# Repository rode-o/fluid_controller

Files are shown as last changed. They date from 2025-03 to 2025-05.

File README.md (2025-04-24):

# Fluid Controller
# WIP

This repository contains software and firmware for a custom fluid control system, featuring PID-based flow rate control, intuitive graphical interfaces, real-time plotting, and reliable hardware communication.

---

## Overview

The project includes two primary components:

- **Controller Interface (GUI)**: A Python-based graphical user interface for real-time monitoring, PID tuning, and easy control of the fluid system.
- **PID Controller (Firmware)**: Arduino-compatible firmware implementing precise PID flow control, valve actuation, sensor reading, and communication logic.

---

## Repository Structure

```
fluid_controller/
│  README.md
│  pid_controller.zip
│
├─ controller_interface/           # PyQt GUI application
│  │  build.bat
│  │  Controller_Interface.spec
│  │  LICENSE
│  │  pyproject.toml
│  │  requirements.txt
│  ├─ build/ …                     # (auto-generated by PyInstaller)
│  ├─ dist/  …                     # frozen executables
│  ├─ src/
│  │  ├─ controller_interface/
│  │  │  ├─ controller/            # high-level UI controller classes
│  │  │  ├─ model/                 # data & serial back-end
│  │  │  ├─ view/                  # views, panels, widgets, themes, plots
│  │  │  ├─ resources/             # .qrc + compiled resources_rc.py
│  │  │  └─ utils/                 # logging & path helpers
│  │  └─ test/                     # GUI unit/integration tests
│  └─ README.md                    # GUI-specific notes
│
├─ curve_tools/                    # ad-hoc analysis / plotting scripts
│  ├─ exp_curve_validation.py
│  └─ plotter.py
│
├─ misc_utils/                     # one-off utilities / images
│  ├─ DOT.py
│  └─ run_tree.png
│
├─ pid_controller/                 # Embedded firmware (Arduino / C++)
│  └─ _controller/
│     ├─ _controller.ino           # entry-point sketch
│     ├─ config.*                  # system-wide constants
│     ├─ pid.*                     # core PID engine
│     ├─ exp_control.*             # exponential gain scheduling
│     ├─ sigmoidal_control.*       # (optional) sigmoidal gain scheduling
│     ├─ constant_voltage_control.*# open-loop calibration mode
│     ├─ filter.*                  # adaptive + EMA filters
│     ├─ flow.*                    # I²C flow-sensor driver
│     ├─ bartels.*                 # pump DAC driver
│     ├─ display.*, buttons.*      # OLED + input HW
│     ├─ report.*                  # CSV / JSON telemetry
│     └─ system_state.h            # shared data struct
│
├─ test_hardware/                  # standalone sketches for bench tests
│  ├─ i2c_check/…
│  ├─ test_buttons/…
│  ├─ test_i2c/…
│  └─ test_sensor/…                # sensor sanity checks
└─ flow_volume.json                # per-concentration flow-volume map

```

---

## Features

### Controller Interface (GUI)

- Real-time data visualization and PID tuning
- User-friendly layout with customizable themes
- Direct serial communication to embedded hardware
- Easy-to-use GUI controls for hardware interaction

### PID Controller Firmware

- Accurate PID control algorithm with dynamic tuning
- Flow rate measurement and regulation
- Adaptive gain control via sigmoidal functions
- Reliable serial communication for GUI integration

---

## Getting Started

### GUI Installation & Usage

**Prerequisites**:

- Python (≥ 3.8)
- Required Python packages (PyQt6/PySide6, numpy, matplotlib)

**Installation**:

```bash
cd controller_interface
pip install -r requirements.txt
```

**Running the GUI**:

```bash
python src/controller_interface/main.py
```

**Building Standalone Executable (Windows)**:

```bash
./build.bat
```

### Firmware Installation & Upload (Arduino)

1. Open the Arduino IDE.
2. Load the sketch `_controller/_controller.ino`.
3. Connect the Arduino board to your computer via USB.
4. Select your Arduino model and COM port.
5. Compile and upload the sketch to the board.

---

## Hardware Testing

Inside the `test_hardware/` folder, you'll find Arduino sketches designed to test:

- I²C communication (`i2c_check`, `test_i2c`)
- Flow sensors (`test_sensor`, `test_sensor_2`)
- Buttons and other inputs (`test_buttons`)

Load these sketches onto your Arduino hardware for troubleshooting and verification purposes.

---

## Dependencies

- Python ≥ 3.8
- PyQt6 / PySide6 (listed in `requirements.txt`)
- numpy, matplotlib (listed in `requirements.txt`)
- Arduino IDE (for firmware)

- Email: [ropeters@valdosta.edu]

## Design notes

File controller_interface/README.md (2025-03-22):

# Fluid Controller
# WIP

This repository contains software and firmware for a custom fluid control system, featuring PID-based flow rate control, intuitive graphical interfaces, real-time plotting, and reliable hardware communication.

---

## Overview

The project includes two primary components:

- **Controller Interface (GUI)**: A Python-based graphical user interface for real-time monitoring, PID tuning, and easy control of the fluid system.
- **PID Controller (Firmware)**: Arduino-compatible firmware implementing precise PID flow control, valve actuation, sensor reading, and communication logic.

---

## Repository Structure

```
fluid_controller/
├── controller_interface/     # GUI software (Python)
│   ├── build/                # Build files
│   ├── dist/                 # Distributable executables
│   └── src/                  # Source code for GUI
│       ├── controller_interface/
│       │   ├── core/         # Backend logic and communication
│       │   ├── gui/          # Graphical interface elements
│       │   └── resources/    # Icons and images
│       └── test/             # Testing scripts
│
├── pid_controller/           # Arduino firmware (C++)
│   └── _controller/
│       ├── config.h/cpp      # System configurations
│       ├── pid.h/cpp         # PID controller logic
│       ├── flow.h/cpp        # Flow sensor logic
│       ├── sigmoidal_control.h/cpp # Advanced gain scheduling
│       └── _controller.ino   # Main Arduino sketch
│
├── test_hardware/            # Arduino sketches for hardware testing
│
├── flow_volume.json          # Flow volume configuration data
├── pid_controller.zip        # Archive of PID controller code
└── README.md                 # Project documentation
```

---

## Features

### Controller Interface (GUI)

- Real-time data visualization and PID tuning
- User-friendly layout with customizable themes
- Direct serial communication to embedded hardware
- Easy-to-use GUI controls for hardware interaction

### PID Controller Firmware

- Accurate PID control algorithm with dynamic tuning
- Flow rate measurement and regulation
- Adaptive gain control via sigmoidal functions
- Reliable serial communication for GUI integration

---

## Getting Started

### GUI Installation & Usage

**Prerequisites**:

- Python (≥ 3.8)
- Required Python packages (PyQt6/PySide6, numpy, matplotlib)

**Installation**:

```bash
cd controller_interface
pip install -r requirements.txt
```

**Running the GUI**:

```bash
python src/controller_interface/main.py
```

**Building Standalone Executable (Windows)**:

```bash
./build.bat
```

### Firmware Installation & Upload (Arduino)

1. Open the Arduino IDE.
2. Load the sketch `_controller/_controller.ino`.
3. Connect the Arduino board to your computer via USB.
4. Select your Arduino model and COM port.
5. Compile and upload the sketch to the board.

---

## Hardware Testing

Inside the `test_hardware/` folder, you'll find Arduino sketches designed to test:

- I²C communication (`i2c_check`, `test_i2c`)
- Flow sensors (`test_sensor`, `test_sensor_2`)
- Buttons and other inputs (`test_buttons`)

Load these sketches onto your Arduino hardware for troubleshooting and verification purposes.

---

## Dependencies

- Python ≥ 3.8
- PyQt6 / PySide6 (listed in `requirements.txt`)
- numpy, matplotlib (listed in `requirements.txt`)
- Arduino IDE (for firmware)

- Email: [ropeters@valdosta.edu]

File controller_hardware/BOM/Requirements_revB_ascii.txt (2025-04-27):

# Solenoid Controller — Manufacturing Package (rev‑B)

* USB‑C PD sink requests 20 V @ 3 A (fallback 15/9/5 V).
* Rails: 24 V (≤2 A) via boost; 3.3 V logic; low‑noise LDO for RF & sensors.
* Actuation: DRV8912‑Q1 drives three Bürkert 6724 valves (100 mA hit, 25 mA hold).
* Pump: mp‑Lowdriver module powers Bartels BP7.
* Flow feedback: Sensirion SLF3S‑0600F via I²C.
* Status RGB LED indicates PD state & faults.
* ESP32‑S3 handles PWM, closed‑loop control, Wi‑Fi comms.

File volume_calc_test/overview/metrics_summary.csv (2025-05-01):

test_name | final_flow_ml | total_time_raw_s | total_time_raw_min | total_volume_raw_ml | total_mass_raw_g | avg_flow_raw | max_flow_raw | avg_temp_raw | total_time_stable_s | total_time_stable_min | total_volume_stable_ml | total_mass_stable_g | avg_flow_stable | max_flow_stable | min_flow_stable | std_flow_stable | rstd_flow_stable | cov_flow_stable | avg_temp_stable | min_temp_stable | max_temp_stable | measured_mass_g | mass_error_pct
cartridge_flow_test_cal_RodePeters_20250429_112158 | 19.3018 | 2335.837 | 38.9306 | 19.3027 | 18.8588 | 0.4962 | 0.551 | 22.2603 | 2255.413 | 37.5902 | 18.7122 | 18.2818 | 0.4978 | 0.54 | 0.47 | 0.005 | 1.0134 | 0.0101 | 22.2525 | 21.78 | 22.67 | 20.36 | 7.960209557341935
cartridge_flow_test_5_RodePeters_20250429_152344 | 15.2667 | 1841.395 | 30.6899 | 15.2667 | 14.9156 | 0.4978 | 0.603 | 23.9297 |  |  |  |  |  |  |  |  |  |  |  |  |  | 15.1 | 1.2362895223792547
cartridge_flow_test_4_RodePeters_20250429_144302 | 18.339 | 2220.019 | 37.0003 | 18.3394 | 17.9176 | 0.4961 | 1.185 | 23.704 | 2137.613 | 35.6269 | 17.744 | 17.3359 | 0.498 | 1.185 | 0.351 | 0.0097 | 1.9479 | 0.0195 | 23.7003 | 23.28 | 24.0 | 17.87 | -0.2656605795418984
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

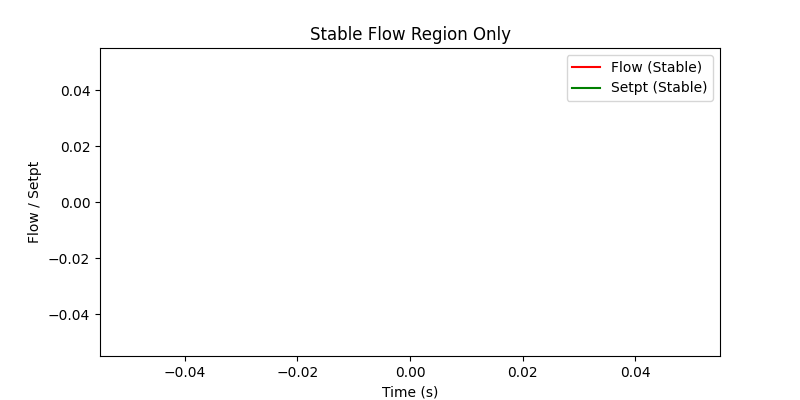
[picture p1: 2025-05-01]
data_demo_1/demo_1_RodePeters_20250508_111236/processed/stable_data/plots/stable_data_plot.png

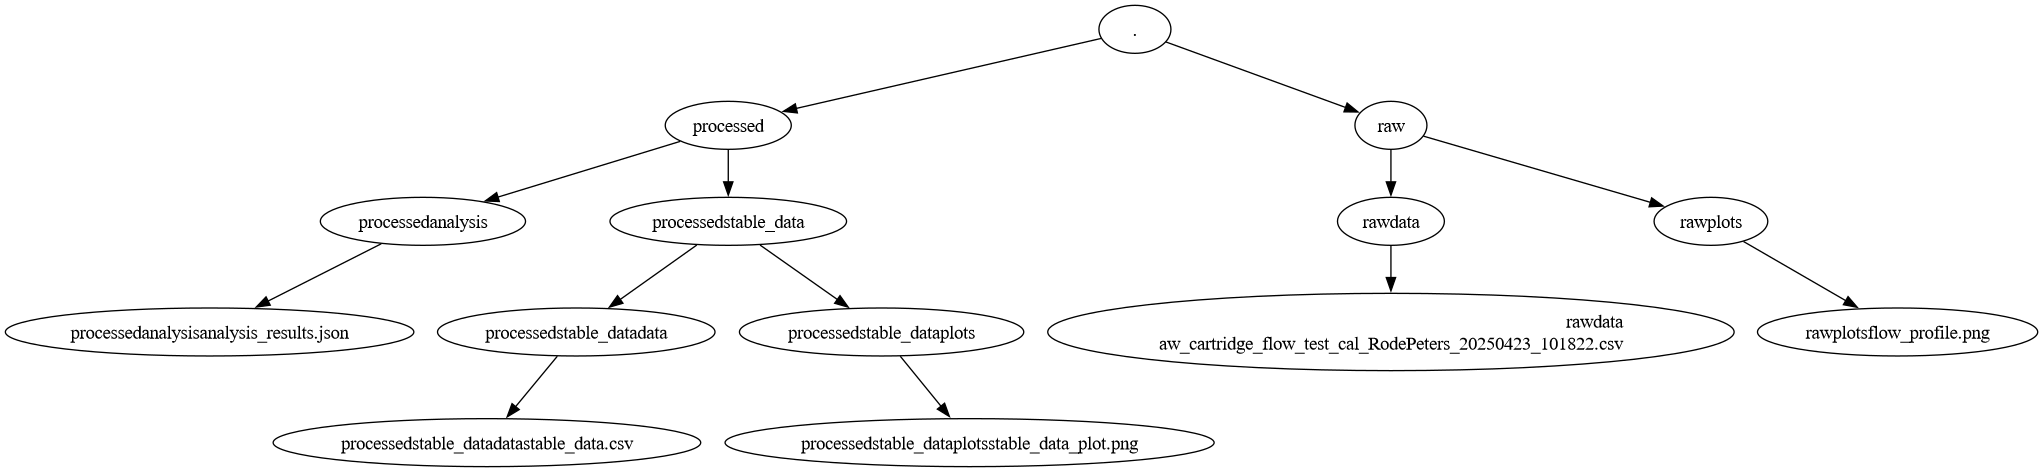
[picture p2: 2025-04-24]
misc_utils/run_tree.png

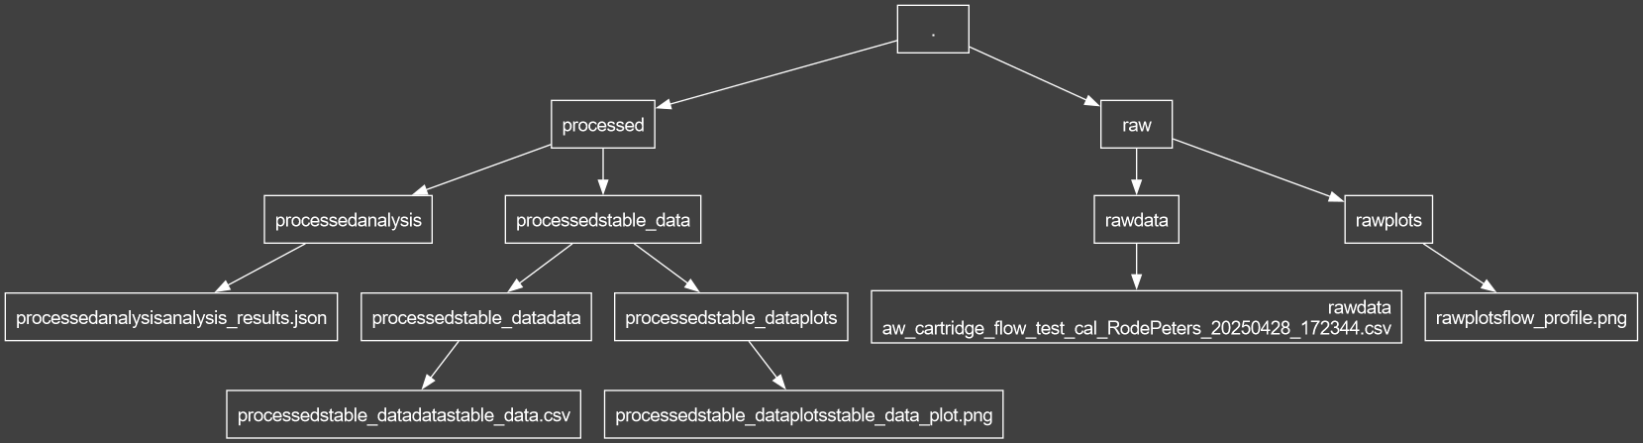
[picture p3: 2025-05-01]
misc_utils/run_tree_white.png

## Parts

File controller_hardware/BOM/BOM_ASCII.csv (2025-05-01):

Part | Ref | Qty | Description | Mfr PN | Digi-Key PN | Unit $ | Ext $
USB4085-GF-A | J1 | 1 | USB-C receptacle, USB2 | GCT USB4085-GF-A | 2073-USB4085-GF-A-ND | 0.65 | 0.65
STUSB4500QTR | U1 | 1 | USB-PD sink controller | ST STUSB4500QTR | 497-18666-1-ND | 2.95 | 2.95
CSD17573Q5B | Q1 | 1 | N‑FET 40V 4.5mOhm | TI CSD17573Q5B | 296-40204-1-ND | 0.45 | 0.45
WE-CAP 220uF 35V | C1 | 1 | Hybrid polymer capacitor | Wurth 860020673012 | 732-860020673012-ND | 0.6 | 0.6
TPS62177DQC | U2 | 1 | Buck 3.3V 0.5A | TI TPS62177DQC | 296-42071-1-ND | 1.19 | 1.19
WE-MPSB 10uH | L1 | 1 | Inductor shielded 10uH 1.6A | Wurth 7447749100 | 732-7447749100-ND | 0.42 | 0.42
TPS73633DBVT | U10 | 1 | LDO 3.3V 400mA | TI TPS73633DBVT | 296-15952-1-ND | 1.22 | 1.22
TPS55340PWP | U3 | 1 | Boost controller 20V to 24V | TI TPS55340PWP | 296-20726-1-ND | 1.74 | 1.74
WE-MAPI 4.7uH | L2 | 1 | Inductor shielded 4.7uH 9A | Wurth 74438357047 | 732-74438357047-ND | 1.08 | 1.08
DRV8908BQPW | U4 | 1 | 4 full-bridge driver | TI DRV8908BQPW | 296-50867-1-ND | 3.95 | 3.95
WE-CAP 47uF 35V | C2 | 1 | Hybrid polymer capacitor | Wurth 860020673006 | 732-860020673006-ND | 0.48 | 0.48
053261-0471 | J2 | 1 | PicoBlade header 4pos | Molex 053261-0471 | WM1734-ND | 0.45 | 0.45
053261-0671 | J3 | 1 | PicoBlade header 6pos | Molex 053261-0671 | WM1736-ND | 0.55 | 0.55
S2B-PH-K-S | J5-J7 | 3 | JST PH header 2pos vert | JST S2B-PH-K-S | 455-1703-ND | 0.1 | 0.30000000000000004
WL-SMCW 150060RS75000 | LED1 | 1 | RGB LED 0603 common anode | Wurth 150060RS75000 | 732-11825-1-ND | 0.19 | 0.19
ESP32-S3-WROOM-1-N8 | U7 | 1 | ESP32-S3 module 8MB | Espressif | 1965-ESP32-S3-WROOM-1-N8-ND | 3.4 | 3.4
110-44-318-41-001000 | J4 | 1 | 18pin socket | Mill‑Max 110-44-318-41-001000 | 110-44-318-41-001000-ND | 2.44 | 2.44
mp-Lowdriver | U8 | 1 | Piezo driver module | Bartels | NA | 42.0 | 42.0
BP7 micropump | PUMP1 | 1 | Piezo micropump | Bartels BP7 | NA | 69.0 | 69.0
SLF3S-0600F | FL1 | 1 | Flow sensor 0‑600uL/min | Sensirion SLF3S‑0600F | 1649-SLF3S-0600F-ND | 29.5 | 29.5
Burkert 6724 valve | V1‑V3 | 3 | 24V micro valve | Burkert 6724 | NA | 58.0 | 174.0
TPD2E2U06DRLR | TVS1 | 1 | USB ESD diode 2‑line | TI TPD2E2U06DRLR | 296‑39231‑1‑ND | 0.25 | 0.25
SBR5U60P5 | D1 | 1 | Schottky 40V 5A | TI SBR5U60P5 | 296‑50472‑1‑ND | 0.3 | 0.3
Misc passives | - | 1 | 0603 resistors capacitors | Various | - | 3.0 | 3.0

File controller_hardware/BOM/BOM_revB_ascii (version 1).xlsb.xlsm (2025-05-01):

Part | Refs | Qty | Description | Manufacturer PN | Digi-Key PN | Ratings | Unit $ | Ext $
USB4085-GF-A | J1 | 1 | USB-C receptacle, USB2 only | GCT USB4085-GF-A | 2073-USB4085-GF-A-ND | 5 A, 25 V, 20k cycles | 0.63 | 0.63
STUSB4500QTR | U1 | 1 | USB-PD sink / power path | ST STUSB4500QTR | 497-18666-1-ND | 5-20 V, 5 A | 3.04 | 3.04
CSD17573Q5B | Q1 | 1 | Power-path N-FET 40 V 4.5 mOhm | TI CSD17573Q5B | 296-40204-1-ND | Id 120 A | 0.45 | 0.45
EEE-FK1V221P | C1 | 1 | Cap 220 uF 35 V | Panasonic EEU-FR1V221L | 667-EEU-FR1V221LCT-ND | ESR 70 mOhm | 0.32 | 0.32
TPS62177DQC | U2 | 1 | Buck 3.3 V 0.5 A | TI TPS62177DQC | 296-42071-1-ND | Vin 4.5-28 V | 1.19 | 1.19
LQH44PN100MPRL | L1 | 1 | Inductor 10 uH 1.2 A | Murata LQH44PN100MPRL | 490-2523-1-ND | DCR 120 mOhm | 0.38 | 0.38
TPS73633DBVT | U10 | 1 | LDO 3.3 V 400 mA | TI TPS73633DBVT | 296-15952-1-ND | Dropout 340 mV | 1.22 | 1.22
TPS55340PWP | U3 | 1 | Boost 20 V to 24 V | TI LM5157DGKR | 296-LM5157DGKR-ND | Switch 42 V 4 A | 2.7 | 2.7
74438357047 | L2 | 1 | Inductor 4.7 uH 8 A | Coilcraft XAL5050-472MEB | 1783-1616-1-ND | DCR 14 mOhm | 1.34 | 1.34
DRV8908BQPW | U4 | 1 | 12-ch half-bridge driver | TI DRV8912-Q1 | 296-54932-1-ND | 40 V, 2 A pk/channel | 4.95 | 4.95
EEE-FK1V470P | C2 | 1 | Cap 47 uF 35 V | Panasonic EEU-FR1V470 | 667-EEU-FR1V470CT-ND | ESR 80 mOhm | 0.28 | 0.28
053261-0471 | J2 | 1 | PicoBlade header 4 pos | Molex 053261-0471 | WM1734-ND | 1 A pin | 0.45 | 0.45
053261-0671 | J3 | 1 | PicoBlade header 6 pos | Molex 053261-0671 | WM1736-ND | 1 A pin | 0.55 | 0.55
S2B-PH-K-S | J5-J7 | 3 | JST PH header 2 pos | JST B2B-PH-KL | 455-1666-1-ND | 3 A pin | 0.12 | 0.36
WL-SMCW 150060RS75000 | LED1 | 1 | RGB LED 0603 | SunLED XZCMECBDDGK53W | 1497-1610-1-ND | 20 mA per color | 0.28 | 0.28
ESP32-S3-WROOM-1-N8 | U7 | 1 | ESP32-S3 module 8 MB | Espressif ESP32-S3-WROOM-1-N8 | 1965-ESP32-S3-WROOM-1-N8-ND | 3.3 V, 500 mA peak | 3.4 | 3.4
110-44-318-41-001000 | J4 | 1 | 18-pin DIP socket | Mill-Max 110-44-318-41-001000 | 110-44-318-41-001000-ND | 1 A pin | 2.44 | 2.44
mp-Lowdriver | U8 | 1 | Piezo driver module | Bartels mp-Lowdriver | NA | +-75 Vpp | 42 | 42
BP7 micropump | PUMP1 | 1 | Piezo micropump | Bartels BP7 | NA | 24 V act, 800 mW | 69 | 69
SLF3S-0600F | FL1 | 1 | Flow sensor 0-600 uL/min | Sensirion SLF3S-0600F | 1649-SLF3S-0600F-ND | 3.3 V, 5 mA | 29.5 | 29.5
Burkert 6724 valve | VALVE1-3 | 3 | Micro solenoid valve 24 V | Burkert 6724 | NA | 24 V 100 mA hit | 58 | 174
TPD2E2U06DRLR | TVS1 | 1 | USB ESD protector | Nexperia PESD5VDUO | 1727-1251-1-ND | +-15 kV | 0.16 | 0.16
Misc passives | - | 1 | Assorted resistors capacitors | Yageo / TDK | NA | Various | 3 | 3

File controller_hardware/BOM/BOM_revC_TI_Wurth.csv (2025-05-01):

Part | Refs | Qty | Description | Manufacturer PN | Digi-Key PN | Unit $ | Ext $
USB4085-GF-A | J1 | 1 | USB‑C receptacle, USB2 | GCT USB4085-GF-A | 2073-USB4085-GF-A-ND | 0.65 | 0.65
STUSB4500QTR | U1 | 1 | USB‑PD sink / power path | ST STUSB4500QTR | 497-18666-1-ND | 2.95 | 2.95
CSD17573Q5B | Q1 | 1 | N‑FET 40 V 4.5 mΩ | TI CSD17573Q5B | 296-40204-1-ND | 0.45 | 0.45
WE‑CAP 220 µF 35 V | C1 | 1 | Hybrid‑polymer bulk cap | Würth 860020673012 | 732-860020673012-ND | 0.6 | 0.6
TPS62177DQC | U2 | 1 | Buck 3.3 V 0.5 A | TI TPS62177DQC | 296-42071-1-ND | 1.19 | 1.19
WE‑MPSB 10 µH | L1 | 1 | Inductor 10 µH 1.6 A | Würth 7447749100 | 732-7447749100-ND | 0.42 | 0.42
TPS73633DBVT | U10 | 1 | LDO 3.3 V 400 mA | TI TPS73633DBVT | 296-15952-1-ND | 1.22 | 1.22
TPS55340PWP | U3 | 1 | Boost ctrl 20→24 V | TI TPS55340PWP | 296-20726-1-ND | 1.74 | 1.74
WE‑MAPI 4.7 µH | L2 | 1 | Inductor 4.7 µH 9 A | Würth 74438357047 | 732-74438357047-ND | 1.08 | 1.08
DRV8908BQPW | U4 | 1 | 8‑half‑bridge driver | TI DRV8908BQPW | 296-50867-1-ND | 3.95 | 3.95
WE‑CAP 47 µF 35 V | C2 | 1 | Hybrid‑polymer cap | Würth 860020673006 | 732-860020673006-ND | 0.48 | 0.48
053261-0471 | J2 | 1 | PicoBlade 4‑pos HDR | Molex 053261‑0471 | WM1734-ND | 0.45 | 0.45
053261-0671 | J3 | 1 | PicoBlade 6‑pos HDR | Molex 053261‑0671 | WM1736-ND | 0.55 | 0.55
S2B-PH-K-S | J5‑J7 | 3 | JST‑PH 2‑pos HDR vert | JST S2B-PH-K-S | 455-1703-ND | 0.1 | 0.30000000000000004
WL‑SMCW 150060RS75000 | LED1 | 1 | RGB LED 0603 CA | Würth 150060RS75000 | 732-11825-1-ND | 0.19 | 0.19
ESP32-S3-WROOM-1-N8 | U7 | 1 | ESP32‑S3 module 8 MB | Espressif | 1965-ESP32-S3-WROOM-1-N8-ND | 3.4 | 3.4
110-44-318-41-001000 | J4 | 1 | 18‑pin socket | Mill‑Max 110‑44‑318‑41‑001000 | 110-44-318-41-001000-ND | 2.44 | 2.44
mp‑Lowdriver | U8 | 1 | Piezo driver module | Bartels | — | 42.0 | 42.0
BP7 micropump | PUMP1 | 1 | Piezo micropump | Bartels BP7 | — | 69.0 | 69.0
SLF3S-0600F | FL1 | 1 | Flow sensor 0‑600 µL/min | Sensirion SLF3S‑0600F | 1649-SLF3S-0600F-ND | 29.5 | 29.5
Burkert 6724 valve | V1‑V3 | 3 | 24 V micro valve | Burkert 6724 | — | 58.0 | 174.0
TPD2E2U06DRLR | TVS1 | 1 | USB ESD diode 2‑line | TI TPD2E2U06DRLR | 296-39231-1-ND | 0.25 | 0.25
SBR5U60P5 | D1 | 1 | Schottky 40 V 5 A | TI SBR5U60P5 | 296-50472-1-ND | 0.3 | 0.3
Misc passives | - | 1 | Rs/Cs, RT, COMP, pull‑ups | — | — | 3.0 | 3.0

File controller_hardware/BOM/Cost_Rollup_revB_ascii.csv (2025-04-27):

Part | Qty | Unit $ | Ext $
USB4085-GF-A | 1 | 0.63 | 0.63
STUSB4500QTR | 1 | 3.04 | 3.04
CSD17573Q5B | 1 | 0.45 | 0.45
EEU-FR1V221L | 1 | 0.32 | 0.32
TPS62177DQC | 1 | 1.19 | 1.19
LQH44PN100MPRL | 1 | 0.38 | 0.38
TPS73633DBVT | 1 | 1.22 | 1.22
LM5157DGKR | 1 | 2.7 | 2.7
XAL5050-472MEB | 1 | 1.34 | 1.34
DRV8912-Q1 | 1 | 4.95 | 4.95
EEU-FR1V470 | 1 | 0.28 | 0.28
053261-0471 | 1 | 0.45 | 0.45
053261-0671 | 1 | 0.55 | 0.55
B2B-PH-KL | 3 | 0.12 | 0.36
XZCMECBDDGK53W | 1 | 0.28 | 0.28
ESP32-S3-WROOM-1-N8 | 1 | 3.4 | 3.4
110-44-318-41-001000 | 1 | 2.44 | 2.44
mp-Lowdriver | 1 | 42.0 | 42.0
BP7 micropump | 1 | 69.0 | 69.0
SLF3S-0600F | 1 | 29.5 | 29.5
Burkert 6724 valve | 3 | 58.0 | 174.0
PESD5VDUO | 1 | 0.16 | 0.16
Misc passives | 1 | 3.0 | 3.0

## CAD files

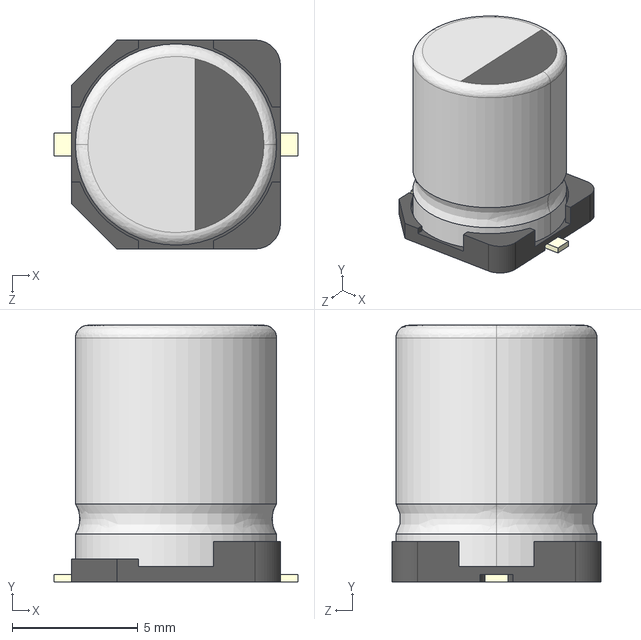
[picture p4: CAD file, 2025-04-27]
controller_hardware/eda/EEE-FK1V221P/EEEFK1V221P.step
9.70 x 10.2 x 8.30 mm

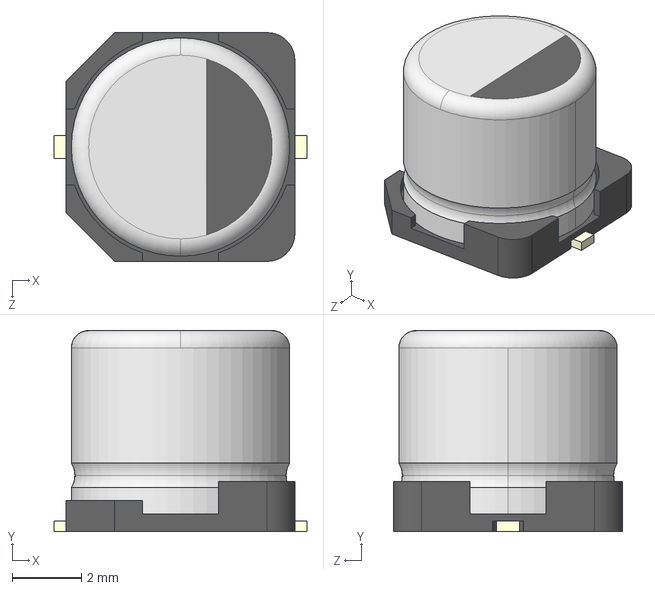
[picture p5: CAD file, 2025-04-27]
controller_hardware/eda/EEE-FK1V470P/EEEFK1V470P.step
7.30 x 5.80 x 6.60 mm

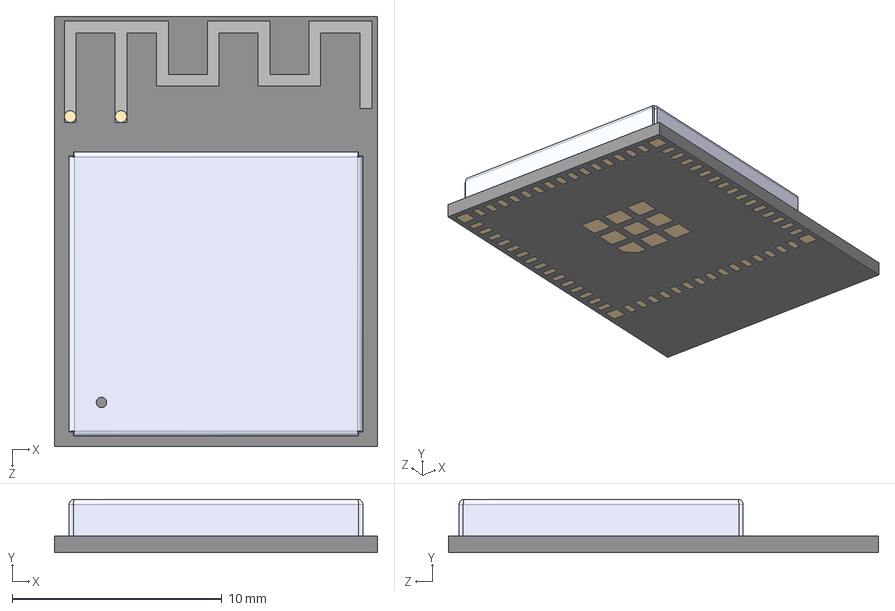
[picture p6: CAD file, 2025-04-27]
controller_hardware/eda/ESP32-S3-MINI-1-N8/ESP32-S3-MINI-1-N8.step
15.4 x 2.55 x 20.5 mm

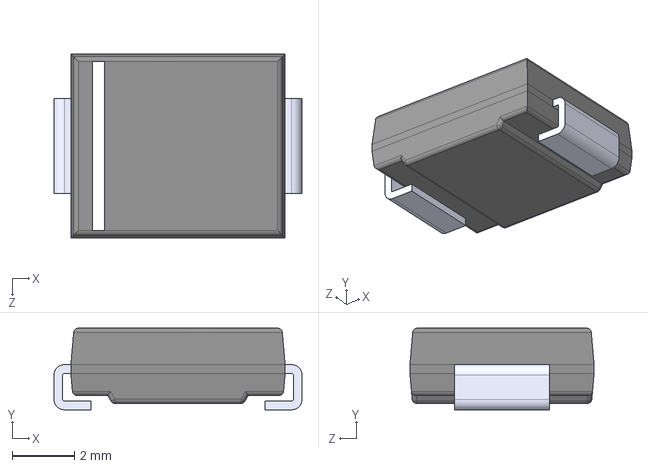
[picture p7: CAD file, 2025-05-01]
controller_hardware/eda/MBRS540T3G/MBRS540T3G.step
7.95 x 2.62 x 5.91 mm

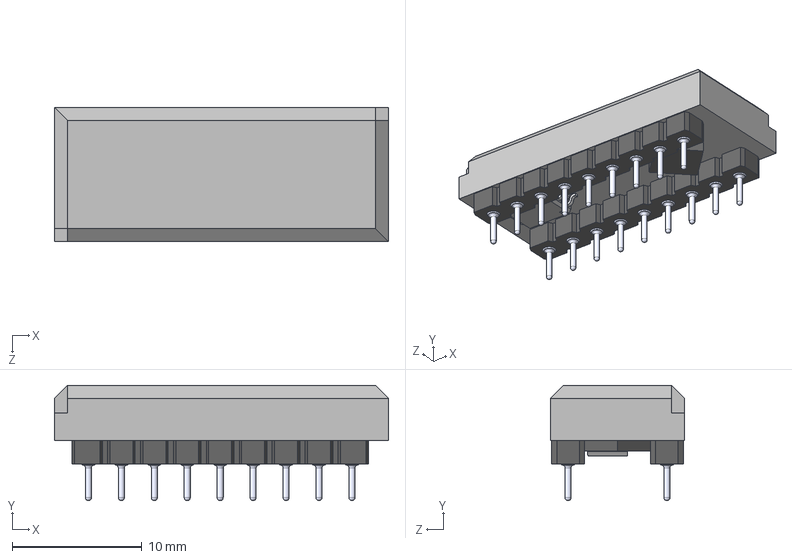
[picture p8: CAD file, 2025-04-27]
controller_hardware/eda/mp_lowdriver---110-87-318-41-001101/mp-Lowdriver 3D model.STEP
25.8 x 8.89 x 10.3 mm
Platine
0603_AVX
D1
pcb_connector_350-80-109-00-019101 x 2
C3
C2
DE41, DE42 x 2
CE41, CE42 x 2
U2
C2 Mitte
C1 Seiten x 2
DE43, DE44 Mitte x 2
D1-SOD323_DIO.step x 4
R11 x 2
U1
L1
Coating_Highdriver

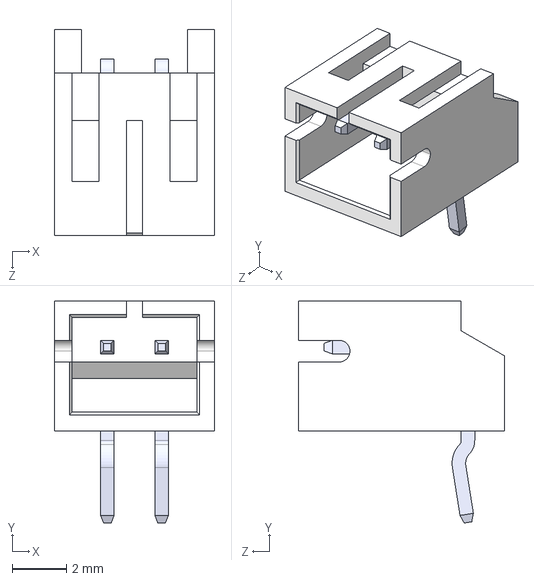
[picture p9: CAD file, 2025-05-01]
controller_hardware/eda/S2B-PH-K-S/S2B-PH-K-S.STEP
5.90 x 8.18 x 7.60 mm

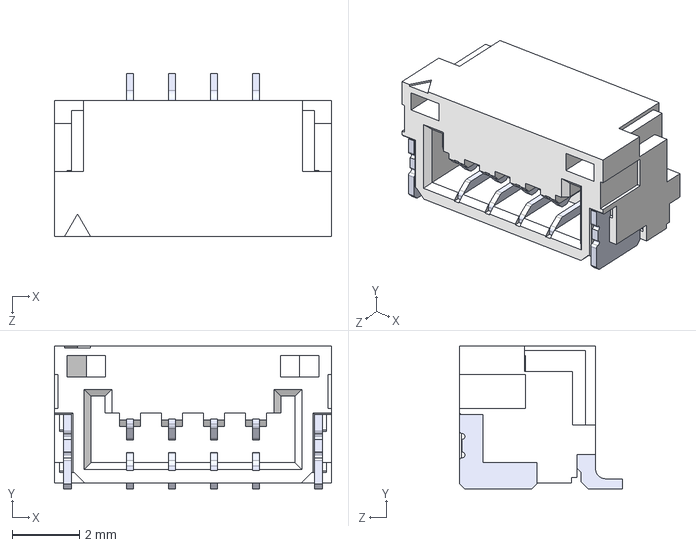
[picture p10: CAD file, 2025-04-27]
controller_hardware/eda/SM04B-GHS-TB_LF__SN_-/SM04B-GHS-TB_LF__SN_-.step
8.25 x 4.25 x 4.85 mm
SMxB-GHS-TB_04
pin x 4

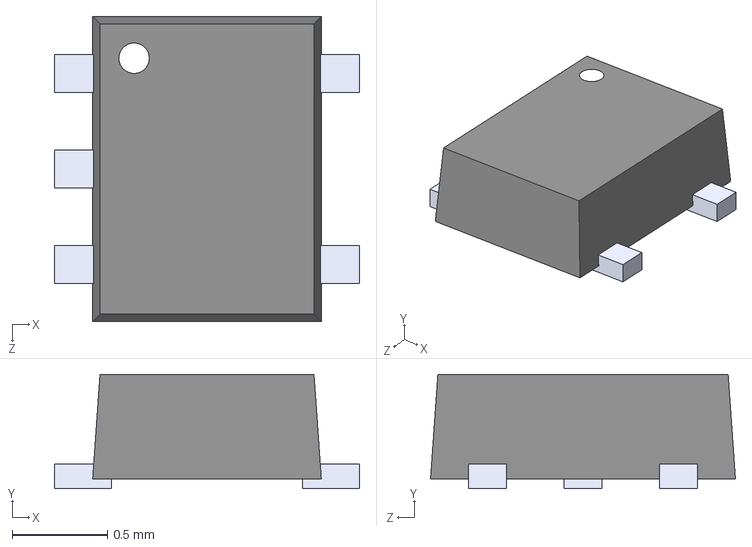
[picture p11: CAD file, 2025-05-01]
controller_hardware/eda/TPD2E2U06DRLR/TPD2E2U06DRLR.step
1.60 x 0.6 x 1.60 mm

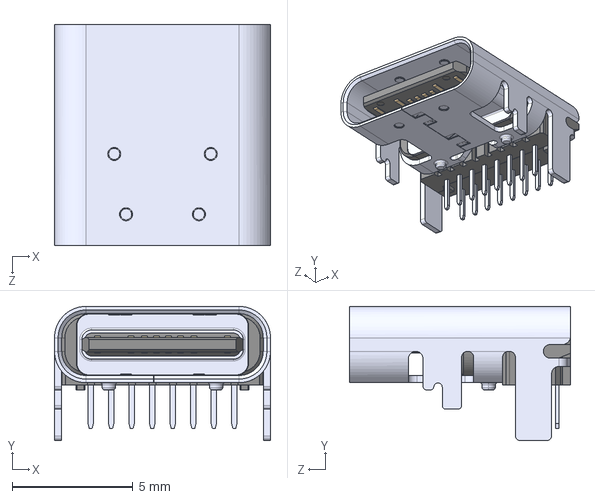
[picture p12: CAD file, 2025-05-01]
controller_hardware/eda/USB4085-GF-A/USB4085-GF-A_REVB.step
8.95 x 5.56 x 9.17 mm

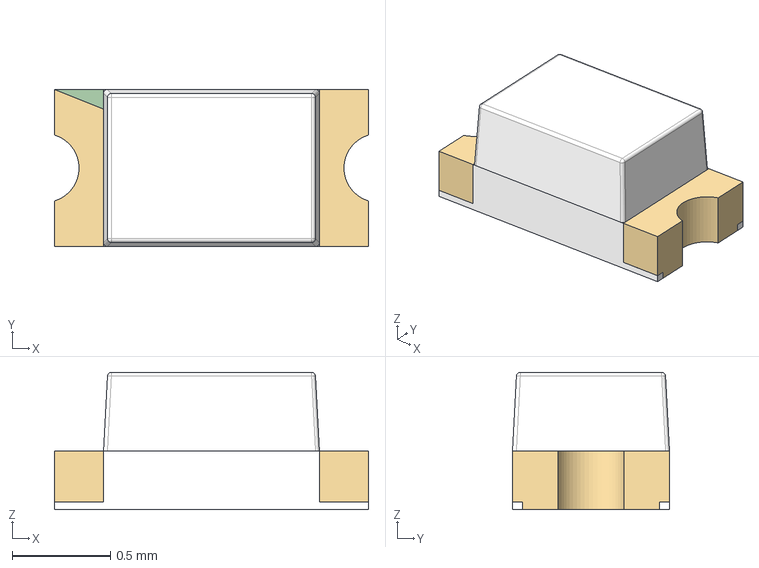
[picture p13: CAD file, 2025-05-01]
controller_hardware/eda/WL-SMCW_0603/WL-SMCW_0603.step
1.60 x 0.8 x 0.7 mm

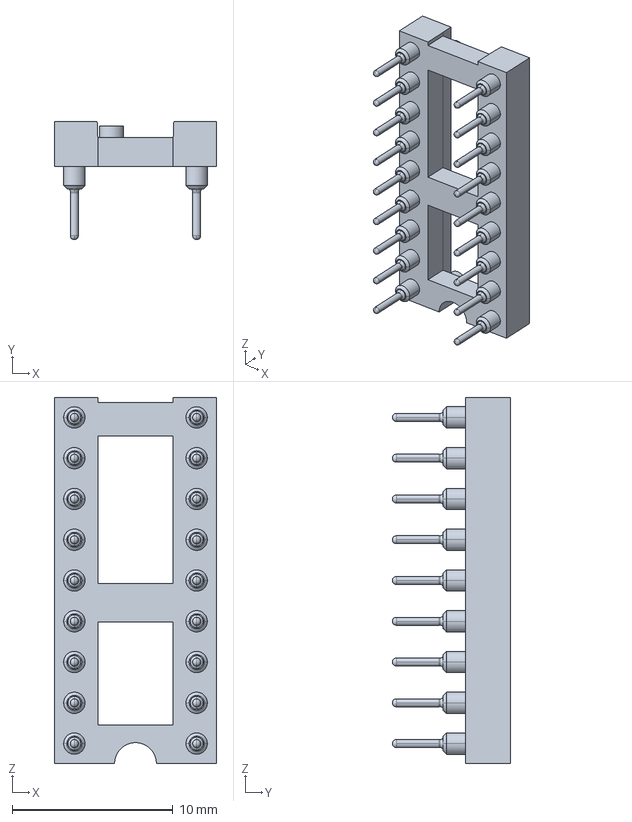
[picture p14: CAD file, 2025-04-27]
controller_hardware/eda/mp_lowdriver---110-87-318-41-001101/dil_socket_110-87-318-41-001101.stp
10.1 x 7.37 x 22.8 mm

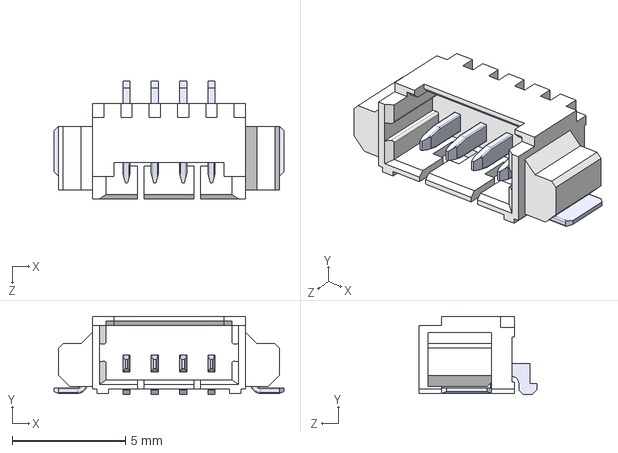
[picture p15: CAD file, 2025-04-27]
controller_hardware/eda/532610x71/4pos/0532610471.step
10.2 x 3.45 x 5.20 mm

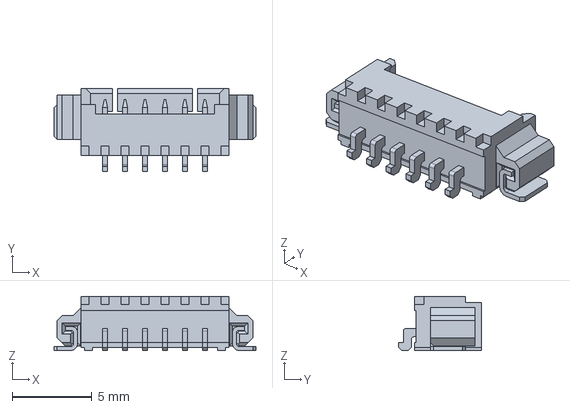
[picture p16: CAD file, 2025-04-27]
controller_hardware/eda/532610x71/6pos/532610671.step
12.7 x 5.20 x 3.40 mm

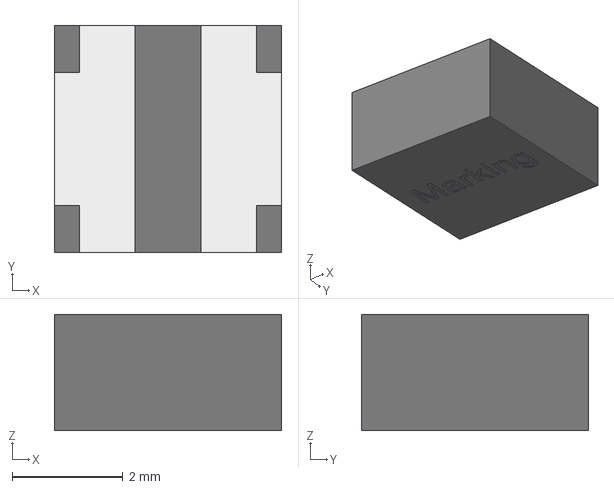
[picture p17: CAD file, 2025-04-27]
controller_hardware/eda/74438357047/74438357047.step
4.10 x 4.10 x 2.10 mm
body_SSMC_4020
land_pattern_SSMC_4020 x 2

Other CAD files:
controller_hardware/eda/875075661008_220/WCAP-PSLC_10X12.4.step
controller_hardware/eda/875105645005_47/WCAP-PSLP_6.3X7.7.step
controller_hardware/eda/TPS55340PWP/TPS55340PWP.step
controller_hardware/eda/TPS73633DBVT/TPS73633DBVTG4.step

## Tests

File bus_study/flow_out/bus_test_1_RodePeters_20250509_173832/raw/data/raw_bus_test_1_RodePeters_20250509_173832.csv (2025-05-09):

absTimeISO | relTimeMs | relTimeSec | relTimeMin | timeMs | flow | setpt | temp | bubble | volt | on | errorPct | pidOut | P | I | D | pGain | iGain | dGain | filteredErr | currentAlpha | totalVolume | userStable
2025-05-09T17:38:33.091425 | 171.14639282226562 | 0.17114639282226562 | 0.0028524398803710938 | 5673359 | 0.016 | 0.5 | 25.8 | False | 0.0 | False | 8.0 | 0.0 | 0.0 | 0.0 | 0.0 | 0.0 | 0.0 | 0.0 | 0.0 | 0.0 | 8.059166632876396 | False
2025-05-09T17:38:33.380500 | 460.2212905883789 | 0.4602212905883789 | 0.007670354843139648 | 5673648 | 0.007 | 0.5 | 25.87 | False | 0.0 | False | 8.0 | 0.0 | 0.0 | 0.0 | 0.0 | 0.0 | 0.0 | 0.0 | 0.0 | 0.0 | 8.059200358258064 | False
2025-05-09T17:38:33.669556 | 749.2771148681641 | 0.7492771148681641 | 0.012487951914469402 | 5673938 | 0.004 | 0.5 | 26.11 | False | 0.0 | False | 8.0 | 0.0 | 0.0 | 0.0 | 0.0 | 0.0 | 0.0 | 0.0 | 0.0 | 0.0 | 8.059219628678063 | False
2025-05-09T17:38:33.960394 | 1040.1146411895752 | 1.0401146411895752 | 0.017335244019826255 | 5674227 | 0.004 | 0.5 | 26.27 | False | 0.0 | False | 8.0 | 0.0 | 0.0 | 0.0 | 0.0 | 0.0 | 0.0 | 0.0 | 0.0 | 0.0 | 8.059239017831397 | False
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

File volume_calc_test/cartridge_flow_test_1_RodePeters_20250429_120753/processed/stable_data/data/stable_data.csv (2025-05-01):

absTimeISO | relTimeMs | relTimeSec | relTimeMin | timeMs | flow | setpt | temp | bubble | volt | on | errorPct | pidOut | P | I | D | pGain | iGain | dGain | filteredErr | currentAlpha | totalVolume | userStable | Time_s
2025-04-29T12:08:29.431625 | 35868.361473083496 | 35.868361473083496 | 0.5978060245513916 | 2960174 | 0.501 | 0.5 | 22.88 | False | 71.23 | True | 8.0 | 0.475 | 0.0 | 0.475 | 0.0 | 0.0 | 0.011 | 0.0 | 0.006 | 0.0 | 0.21132015718333 | True | 2960.174
2025-04-29T12:08:29.592872 | 36029.608488082886 | 36.029608488082886 | 0.6004934748013814 | 2960333 | 0.499 | 0.5 | 22.89 | False | 71.23 | True | 8.0 | 0.475 | 0.0 | 0.475 | 0.0 | 0.0 | 0.011 | 0.0 | 0.006 | 0.0 | 0.2126612022183341 | True | 2960.333
2025-04-29T12:08:29.747741 | 36184.47732925415 | 36.18447732925415 | 0.6030746221542358 | 2960492 | 0.496 | 0.5 | 23.0 | False | 71.23 | True | 8.0 | 0.475 | 0.0 | 0.475 | 0.0 | 0.0 | 0.01 | 0.0 | 0.006 | 0.042 | 0.2139414559250031 | True | 2960.492
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

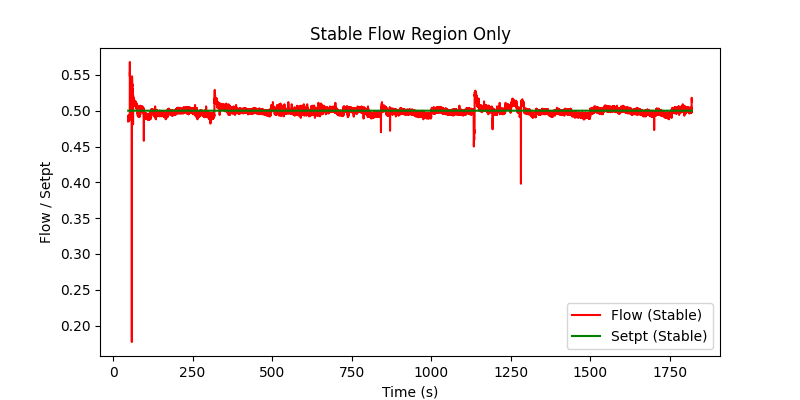
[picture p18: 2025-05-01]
volume_calc_test/cartridge_flow_test_3_RodePeters_20250429_140705/processed/stable_data/plots/stable_data_plot.png

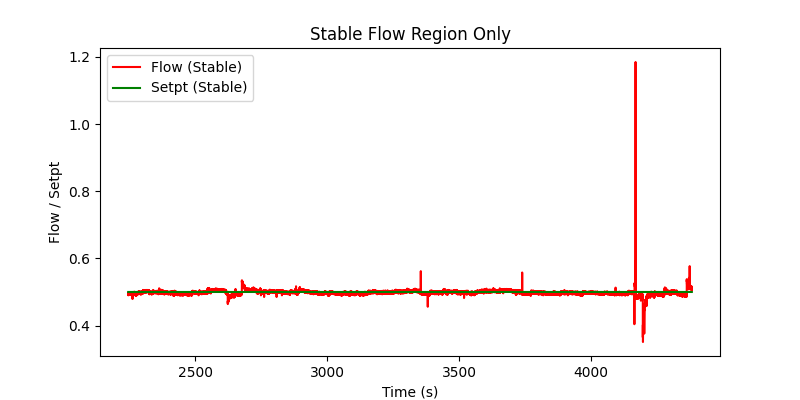
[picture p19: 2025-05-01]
volume_calc_test/cartridge_flow_test_4_RodePeters_20250429_144302/processed/stable_data/plots/stable_data_plot.png

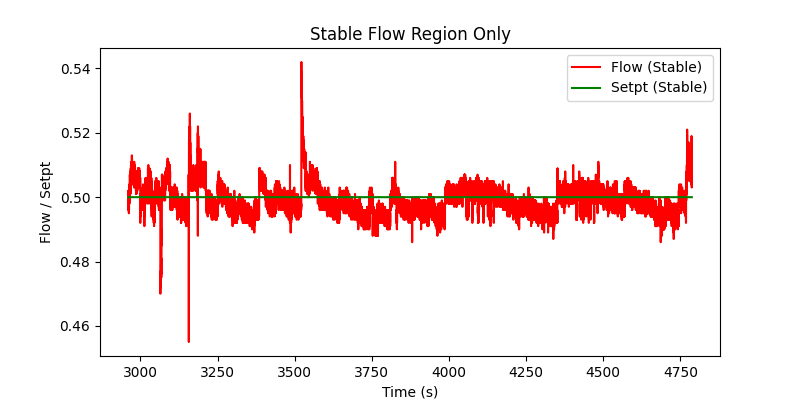
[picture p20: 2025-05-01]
volume_calc_test/cartridge_flow_test_1_RodePeters_20250429_120753/processed/stable_data/plots/stable_data_plot.png

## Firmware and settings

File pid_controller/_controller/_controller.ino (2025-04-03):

#include <Arduino.h>
#include <Wire.h>
#include <EEPROM.h>

// Project headers
#include "config.h"
#include "flow.h"
#include "bartels.h"
#include "buttons.h"
#include "pid.h"
#include "display.h"
#include "report.h"
// Removed old includes:
// #include "sigmoidal_control.h"
// #include "log_control.h"
#include "exp_control.h"  // Exponential-based control
#include "constant_voltage_control.h"
#include "filter.h"

// Combined runtime state
#include "system_state.h"

// Global system state
static SystemState g_systemState;

// Timing and reporting flags
static unsigned long startTime = 0;
static bool timeReportingEnabled = false;

// Track systemOn transitions in the main loop
static bool previousSystemOn = false;

void setup() {
    Serial.begin(115200);
    Wire.begin();
    EEPROM.begin(512);

    initButtons();
    initBartels();
    initDisplay();

    // Default control mode => EXP
    g_systemState.controlMode = CONTROL_MODE_EXP;

    // Initialize control modules
    initExpController(g_systemState); 
    initConstantVoltageControl();

    // Start flow measurement
    bool ok = startFlowMeasurement();
    if (!ok) {
        Serial.println("[MAIN DEBUG] startFlowMeasurement() failed (I2C error?).");
    }

    startTime = millis();
    Serial.println("[MAIN DEBUG] Setup complete. Entering main loop...");
}

void loop() {
    // 1) Check serial input for time-report toggle
    if (Serial.available() > 0) {
        char c = Serial.read();
        if (c == 'T' || c == 't') {
            timeReportingEnabled = !timeReportingEnabled;
            Serial.print("[MAIN DEBUG] Timing report: ");
            Serial.println(timeReportingEnabled ? "ENABLED" : "DISABLED");
        }
    }

    // 2) Update system-on state from buttons
    updateButtons();
    bool currentSystemOn = isSystemOn();
    g_systemState.systemOn = currentSystemOn;

    // Detect OFF->ON or ON->OFF transitions here in the main loop
    if (!previousSystemOn && currentSystemOn) {
        // System just turned ON
        Serial.println("[MAIN DEBUG] System turned ON (main loop) -> initExpController()");
        initExpController(g_systemState);
    } 
    else if (previousSystemOn && !currentSystemOn) {
        // System just turned OFF
        Serial.println("[MAIN DEBUG] System turned OFF (main loop) -> initExpController()");
        initExpController(g_systemState);
        // Optionally stop pump
        // stopPump();
    }
    previousSystemOn = currentSystemOn;

    // 3) Toggle control mode if requested
    if (wasModeTogglePressed()) {
        // Flip between EXP and CONST_VOLTAGE
        if (g_systemState.controlMode == CONTROL_MODE_EXP) {
            g_systemState.controlMode = CONTROL_MODE_CONST_VOLTAGE;
            Serial.println("[MAIN DEBUG] Mode changed -> CONSTANT VOLTAGE");
        } else {
            g_systemState.controlMode = CONTROL_MODE_EXP;
            Serial.println("[MAIN DEBUG] Mode changed -> EXP CONTROL");
        }
    }

    // 4) Acquire sensor inputs
    g_systemState.flow         = readFlow();
    g_systemState.setpoint     = getFlowSetpoint();
    g_systemState.errorPercent = getErrorPercent();
    g_systemState.temperature  = getTempC();

    uint16_t flags = getLastFlags();
    g_systemState.bubbleDetected = ((flags & (1 << 0)) != 0);

    // 5) Control logic
    float desiredVoltage = 0.0f;
    float pidFraction    = 0.0f;
    float pTerm          = 0.0f;
    float iTerm          = 0.0f;
    float dTerm          = 0.0f;

    if (g_systemState.systemOn) {
        switch (g_systemState.controlMode) {
            case CONTROL_MODE_EXP:
                Serial.println("[MAIN DEBUG] (ON) Calling updateExpController()...");
                updateExpController(
                    g_systemState,
                    g_systemState.flow,
                    g_systemState.setpoint,
                    g_systemState.errorPercent,
                    g_systemState.systemOn,
                    desiredVoltage,
                    pidFraction,
                    g_systemState.bubbleDetected,
                    pTerm,
                    iTerm,
                    dTerm
                );
                Serial.println("[MAIN DEBUG] Returned from updateExpController()");
                break;

            case CONTROL_MODE_CONST_VOLTAGE:
                Serial.println("[MAIN DEBUG] (ON) Calling updateConstantVoltageControl()...");
                updateConstantVoltageControl(g_systemState.systemOn, desiredVoltage);
                Serial.println("[MAIN DEBUG] Returned from updateConstantVoltageControl()");
                break;
        }
    } else {
        // If system is OFF, no controller updates
        stopPump();
        desiredVoltage = 0.0f;
        pidFraction = 0.0f;
        pTerm = 0.0f;
        iTerm = 0.0f;
        dTerm = 0.0f;
    }

    // 6) Save final results in g_systemState
    g_systemState.desiredVoltage = desiredVoltage;
    g_systemState.pidOutput      = pidFraction;
    g_systemState.pTerm          = pTerm;
    g_systemState.iTerm          = iTerm;
    g_systemState.dTerm          = dTerm;

    // 7) Display the current status
    showStatus(
        g_systemState.flow,
        g_systemState.setpoint,
        g_systemState.errorPercent,
        g_systemState.desiredVoltage,
        g_systemState.systemOn,
        g_systemState.temperature,
        g_systemState.bubbleDetected
    );

    // 8) JSON reporting
    g_systemState.currentTimeMs = millis();
    reportAllStateJSON(g_systemState);

    // 9) Auto-stop if run duration exceeded
    unsigned long elapsed = (g_systemState.currentTimeMs - startTime) / 1000UL;
    if (elapsed > SLF_RUN_DURATION) {
        stopFlowMeasurement();
        stopPump();
        Serial.println("[MAIN DEBUG] Timer expired. Flow + pump stopped.");
        while (true) {
            delay(100);
        }
    }

    // 10) Delay loop
    delay(MAIN_LOOP_DELAY_MS);

    // 11) Optional timing info
    if (timeReportingEnabled) {
        Serial.println("[MAIN DEBUG] Loop iteration complete.");
    }

    // 12) Loop frequency measurement
    static unsigned long loopCount       = 0;
    static unsigned long lastFreqCheckMs = 0;
    loopCount++;
    unsigned long nowMs = millis();
    if (nowMs - lastFreqCheckMs >= 2000UL) {
        float loopsPerSecond =
            1000.0f * (static_cast<float>(loopCount) / (nowMs - lastFreqCheckMs));

        Serial.print("[MAIN DEBUG] ~");
        Serial.print(loopsPerSecond, 2);
        Serial.println(" Hz loop frequency.");

        loopCount = 0;
        lastFreqCheckMs = nowMs;
    }
}

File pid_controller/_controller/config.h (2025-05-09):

#pragma once
#include <Arduino.h>

/*
 * File: config.h
 * Brief: Central configuration for display, pump driver, flow sensor,
 *        PID parameters, and other system-wide settings.
 */

// ---------------------------------------------------------------------------
// Constant Voltage Control
// ---------------------------------------------------------------------------
static const float kConstantVoltage = 80.0f; // Used in constant-voltage control mode


// ---------------------------------------------------------------------------
// Display
// ---------------------------------------------------------------------------
static const uint8_t SSD1306_DISPLAY_ADDR = 0x3C;


// ---------------------------------------------------------------------------
// Bartels Pump Driver
// ---------------------------------------------------------------------------
static const uint8_t BARTELS_DRIVER_ADDR   = 0x59;
static const uint8_t BARTELS_PAGE_REGISTER = 0xFF;
static const uint8_t BARTELS_CONTROL_DATA[] = {0x00, 0x3B, 0x01, 0x01};

static const float BARTELS_FREQ         = 300.0f;  // Desired pump frequency in Hz
static const float BARTELS_ABSOLUTE_MAX = 150.0f;
static const float BARTELS_MAX_VOLTAGE  = 150.0f;
static const float BARTELS_MIN_VOLTAGE  = 0.0f;


// ---------------------------------------------------------------------------
// Flow Sensor
// ---------------------------------------------------------------------------
static const uint8_t SLF_FLOW_SENSOR_ADDR     = 0x08;
static const uint8_t SLF_START_CMD            = 0x36;
static const uint8_t SLF_CALIBRATION_CMD_BYTE = 0x08;
static const uint8_t SLF_STOP_CMD             = 0x3F;
static const uint8_t SLF_STOP_BYTE            = 0xF9;

static const float SLF_SCALE_FACTOR_FLOW = 10000.0f;
static const float SLF_SCALE_FACTOR_TEMP = 200.0f;

// Maximum run duration (seconds) before auto-stop
static const float SLF_RUN_DURATION = 36000.0f; 


// ---------------------------------------------------------------------------
// Flow/Error Ranges
// ---------------------------------------------------------------------------
static const float FLOW_SP_MIN       = 0.0f;
static const float FLOW_SP_MAX       = 2.0f;
static const float ERROR_PERCENT_MIN = -50.0f;
static const float ERROR_PERCENT_MAX =  50.0f;

/**
 * FLOW_STEP_SIZE:
 *   Step amount for adjusting the flow setpoint via button presses (in buttons.cpp).
 */
static const float FLOW_STEP_SIZE = 0.05f;


// ---------------------------------------------------------------------------
// Exponential Gain Parameters for PID
//   f(x) = A + (K - A)*exp(-(1/B)*(x - C))
// ---------------------------------------------------------------------------

// Kp parameters
#define EXP_KP_A  0.0f
#define EXP_KP_K  0.0f
#define EXP_KP_B  0.0f
#define EXP_KP_C  0.0f

// Ki parameters
#define EXP_KI_A  0.001f
#define EXP_KI_K  0.23f
#define EXP_KI_B  100.0f
#define EXP_KI_C  0.0f

// Kd parameters
#define EXP_KD_A  0.0f
#define EXP_KD_K  0.0f
#define EXP_KD_B  0.0f
#define EXP_KD_C  0.0f


// ---------------------------------------------------------------------------
// Filter / Slope-Matching Parameters
// ---------------------------------------------------------------------------
/**
 * FILTER_T_REF:
 *   The reference "time" or error at which we match slopes for
 *   the primary vs. secondary exponential function.
 */
static const float FILTER_T_REF = 0.05f;

/**
 * FILTER_SECONDARY_A2 / K2:
 *   For the secondary function f2(t) = A2 + (K2 - A2)*exp(-1/(B2*t)),
 *   often pinned A2=0, K2=1 for slope matching approach.
 */
static const float FILTER_SECONDARY_A2 = 0.0f;
static const float FILTER_SECONDARY_K2 = 0.5f;

/**
 * FILTER_B2_GUESS:
 *   Initial guess for numeric solving to find B2.
 */
static const float FILTER_B2_GUESS = 3.0f;

// ─── Extra EMA pole ──────────────────────────────────────────────
// α close to 1.0  → heavy smoothing, more delay
// α close to 0.0  → no smoothing
#define EMA_ALPHA   0.85f          


// ---------------------------------------------------------------------------
// (Optional) Legacy logistic-based LPF params (you can remove if not in use)
// ---------------------------------------------------------------------------
static const float LPF_ALPHA_BASE      = 0.0f; 
static const float LPF_ALPHA_AMPLITUDE = 1.0f; 
static const float LPF_ALPHA_SLOPE     = 2000.0f; 
static const float LPF_ALPHA_MIDPOINT  = 0.005f;


// ---------------------------------------------------------------------------
// PID Configuration
// ---------------------------------------------------------------------------
static const float PID_ANTIWINDUP_GAIN    = 0.1f;
static const float PID_DERIV_FILTER_ALPHA = 0.8f;
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

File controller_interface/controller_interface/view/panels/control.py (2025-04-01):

# controller_interface/view/panels/control.py

import os
import serial.tools.list_ports

from PyQt5.QtWidgets import (
    QGroupBox, QVBoxLayout, QHBoxLayout, QLabel, QComboBox,
    QDoubleSpinBox, QFileDialog, QLineEdit, QFrame, QSizePolicy
)
from PyQt5.QtCore import pyqtSignal, Qt, QSettings
from PyQt5.QtGui import QFont, QPalette, QColor

from controller_interface.view.widgets.themed_button import ThemedButton

TITLE_COLOR_RGB = (29, 154, 221)
TITLE_FONT_SIZE = 12
CHILD_FONT_SIZE = 12

class TuningControlPanel(QGroupBox):
    """
    A QGroupBox with:
      - Port selection, baud, time window
      - Data Root in its own row (displays only the last path element)
      - Test Name on its own row
      - "Change Dir" on its own row
      - Fluid Density input
      - Start/Stop
      - A 'Mark Stable' toggle.
    """

    startSignal = pyqtSignal()
    stopSignal = pyqtSignal()
    stabilityChanged = pyqtSignal(bool)

    def __init__(self, parent=None, settings: QSettings | None = None):
        super().__init__(parent)
        self.setTitle("Tuning Control Panel")
        self.settings = settings
        self.data_root: str | None = None

        # -----------------------
        # 1) Title font & color
        # -----------------------
        title_font = QFont()
        title_font.setPointSize(TITLE_FONT_SIZE)
        title_font.setBold(True)
        self.setFont(title_font)

        palette = self.palette()
        palette.setColor(self.foregroundRole(), QColor(*TITLE_COLOR_RGB))
        self.setPalette(palette)

        # -----------------------
        # 2) Child font
        # -----------------------
        self.child_font = QFont()
        self.child_font.setPointSize(CHILD_FONT_SIZE)
        self.child_font.setBold(False)

        # -----------------------
        # Main layout
        # -----------------------
        main_layout = QVBoxLayout(self)
        # Keep margins small to avoid unnecessary space
        main_layout.setContentsMargins(5, 5, 5, 5)
        # Reduce spacing from 20 -> 8 or 10 so it doesn't look too large
        main_layout.setSpacing(10)

        # Row 1: Port / Refresh
        row1 = QHBoxLayout()
        self.port_combo = QComboBox(font=self.child_font)
        row1.addWidget(self.port_combo)

        self.btn_refresh = ThemedButton("Refresh Ports", is_dark=False)
        self.btn_refresh.setFont(self.child_font)
        self.btn_refresh.clicked.connect(self._on_refresh_ports_clicked)
        row1.addWidget(self.btn_refresh)
        main_layout.addLayout(row1)

        # Row 2: Baud
        row2 = QHBoxLayout()
        lbl_baud = QLabel("Baud:", font=self.child_font)
        row2.addWidget(lbl_baud)

        self.baud_combo = QComboBox(font=self.child_font)
        self.baud_combo.addItems([
            "9600", "19200", "38400", "57600",
            "115200", "230400"
        ])
        row2.addWidget(self.baud_combo)
        main_layout.addLayout(row2)

        # Row 3: Time Window
        row3 = QHBoxLayout()
        lbl_tw = QLabel("Time Window (s):", font=self.child_font)
        row3.addWidget(lbl_tw)

        self.time_window_spin = QDoubleSpinBox(font=self.child_font)
        self.time_window_spin.setRange(0.0, 9999.0)
        self.time_window_spin.setDecimals(1)
        self.time_window_spin.setValue(10.0)
        row3.addWidget(self.time_window_spin)
        main_layout.addLayout(row3)

        # Row 4: Data Root
        row4 = QHBoxLayout()
        lbl_dir = QLabel("Data Root:", font=self.child_font)
        row4.addWidget(lbl_dir)

        self.lbl_data_root = QLabel("(No directory)", font=self.child_font)
        self.lbl_data_root.setFrameShape(QFrame.Box)
        self.lbl_data_root.setFrameShadow(QFrame.Sunken)
        self.lbl_data_root.setLineWidth(2)
        row4.addWidget(self.lbl_data_root, stretch=2)
        main_layout.addLayout(row4)

        # Row 5: Test Name
        row5 = QHBoxLayout()
        lbl_test = QLabel("Test Name:", font=self.child_font)
        row5.addWidget(lbl_test)

        self.line_test_name = QLineEdit(font=self.child_font)
        self.line_test_name.setPlaceholderText("e.g. test_run_01")
        row5.addWidget(self.line_test_name)
        main_layout.addLayout(row5)

        # Row 6: Change Dir button
        row6 = QHBoxLayout()
        self.btn_change_dir = ThemedButton("Change Dir", is_dark=False)
        self.btn_change_dir.setFont(self.child_font)
        self.btn_change_dir.clicked.connect(self._on_change_dir_clicked)
        row6.addWidget(self.btn_change_dir)
        main_layout.addLayout(row6)

        # Row 7: Fluid Density
        row_density = QHBoxLayout()
        lbl_density = QLabel("Fluid Density (g/mL):", font=self.child_font)
        row_density.addWidget(lbl_density)

        self.fluid_density_spin = QDoubleSpinBox(font=self.child_font)
        self.fluid_density_spin.setRange(0.0, 5.0)
        self.fluid_density_spin.setDecimals(3)
        self.fluid_density_spin.setValue(1.000)
        row_density.addWidget(self.fluid_density_spin)
        main_layout.addLayout(row_density)

        # Row 8: Mark Data as Stable
        row_stable = QHBoxLayout()
        self.btn_stable = ThemedButton("Mark Data as Stable", is_dark=False)
        self.btn_stable.setFont(self.child_font)
        self.btn_stable.setCheckable(True)
        self.btn_stable.setChecked(False)
        self.btn_stable.toggled.connect(self._on_stable_toggled)
        row_stable.addWidget(self.btn_stable)
        main_layout.addLayout(row_stable)

        # Row 9: Start / Stop
        row_startstop = QHBoxLayout()
        self.btn_start = ThemedButton("Start", is_dark=True)
        self.btn_start.setFont(self.child_font)
        self.btn_stop = ThemedButton("Stop", is_dark=False)
        self.btn_stop.setFont(self.child_font)
        self.btn_stop.setEnabled(False)

        self.btn_start.clicked.connect(self._on_start_clicked)
        self.btn_stop.clicked.connect(self._on_stop_clicked)

        row_startstop.addWidget(self.btn_start)
        row_startstop.addWidget(self.btn_stop)
        main_layout.addLayout(row_startstop)

        # Set a size policy that does not expand more than necessary
        # horizontally or vertically.
        self.setSizePolicy(QSizePolicy.Preferred, QSizePolicy.Preferred)

        self.setLayout(main_layout)

        # Initial port refresh
        self.refresh_ports()

    # ----------------------------------------------------------------
    # Load/save logic
    # ----------------------------------------------------------------
    def load_settings(self) -> None:
        """Load any previously stored settings."""
        if self.settings:
            root = self.settings.value("tuning_data_root", "")
            if root:
                self.set_data_root(str(root))

            test_name = self.settings.value("tuning_test_name", "")
            if test_name:
                self.set_test_name(str(test_name))
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

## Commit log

2025-03-31 refactor to MVC codebase / broke some stuff
    [_controller.ino, analysis.py, buttons.cpp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]
2025-04-01 bug fixes and csv output time update to support relative time
    [_controller.ino, analysis.py, buttons.cpp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]
2025-04-03 changed plot_manager layout and data routing, replaced sigmoid control function with custom exp for more simple tuning and fine control
    [_controller.ino, config.h]
2025-04-24 further pid tuning and additional EMA added inline with LPF alpha gain scheduler
2025-04-27 adding initial PCB BOM and KC files
    [0532610471.step, 532610671.step, ESP32-S3-MINI-1-N8.step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]
2025-04-27 added more eda and spice models
    [74438357047.step, BOM_revB_ascii.csv, Cost_Rollup_revB_ascii.csv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]
2025-04-28 changed errorPercent calculation to be ambiguous with ((meas - exp) / exp)*100)
    [BOM_revB_ascii.csv]
2025-05-01 just pushing for fun
    [BOM_ASCII.csv, BOM_revB_ascii (version 1).xlsb.csv, BOM_revB_ascii (version 1).xlsb.xlsm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]
2025-05-09 added intial bus study script and some firmware control parameter tweaking
    [raw_bus_test_1_RodePeters_20250509_173832.csv, raw_demo_1_RodePeters_20250508_111236.csv, raw_demo_1_RodePeters_20250509_153728.csv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]
